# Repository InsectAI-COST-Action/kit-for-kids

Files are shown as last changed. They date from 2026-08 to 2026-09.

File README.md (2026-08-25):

# InsectAI kit-for-kids



An open, DIY insect-camera kit designed to help children aged 8-12 explore insects, ecology, and computer vision through hands-on investigation.

Developed as part of the [InsectAI COST Action](https://www.cost.eu/actions/CA22129/), the project aims to create a classroom-friendly kit that can be built with supervision in around an hour, packaged compactly, and made at scale for under €50. The kit will pair accessible hardware with learning materials for teachers, parents, and young people.

## What we are designing

The kit is being co-designed with educators, researchers, makers, and children. It will support open-ended activities such as observing insect behaviour, testing simple ecological questions, and interpreting results. Proposed hardware includes an ESP32 camera, power bank, and microSD storage, with optional modular components such as habitats, lighting, lenses, or mazes.

AI is intended to support learning, for example by helping to count insects, track movement, recognise patterns, or assist species identification, while keeping its limits visible and leaving interpretation with learners.

## Design principles

- **Children as investigators:** build, observe, test, and interpret.
- **Ecology first:** connect activities to real insects, habitats, and behaviour.
- **Modular and reusable:** adapt the kit for different experiments, lessons, and settings.
- **Low-cost and practical:** robust, portable, and suitable for ordinary classrooms.
- **Open and accessible:** share designs and resources so makerspaces and educators can replicate and adapt them.

## Status

This repository is at the co-design and prototyping stage. Future work will develop and test prototype concepts, refine the hardware and educational resources, and explore suitable on-device and cloud-supported AI approaches.

## Prototype software

- [`software/TomA-insect-ESP32-software`](software/TomA-insect-ESP32-software/): ESP32-S3/OV3660 pilot firmware, SD-card logger, offline dashboard, and accompanying test and operating documentation.
- [`models`](models/): Initial detection models in YOLO26, ONNX, and ESPDet-Pico formats, along with scripts for deploying to ESP32-S3 devices.
- [`datasets`](datasets/): Full training datasets for detection models, with annotations in YOLO format.

## Contributing

We welcome ideas and contributions from educators, children's-learning specialists, entomologists, makers, hardware and software developers, and community organisations. Please open an issue or discussion to propose an experiment, kit feature, learning resource, or collaboration.

## Licence

This project is released under the [MIT License](LICENSE).

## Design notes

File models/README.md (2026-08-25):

# Models

Detection models are currently provided in three formats for testing, [YOLO26](https://github.com/ultralytics/yolo26) as the base format for conversion, [ONNX](https://github.com/onnx/onnx) for browser-based [dashboard](software/TomA-insect-ESP32-software) inference, and [ESPDet-Pico](https://github.com/espressif/esp-detection) for edge deployment on an ESP32-S3. Models are named based upon their corresponding training [dataset](https://github.com/InsectAI-COST-Action/kit-for-kids/tree/main/datasets/) to ensure reproducibility and enable retraining with additional architectures.

## Installation

For simplicity, the YOLO26 and ONNX models can be tested through the standard Ultralytics CLI, however the ESPDet-Pico model must be deployed to an ESP32-S3 via the [deploy](/models/deploy) pipeline. These frameworks are provided for testing rather than integration, and thus should primarily be used for model evaluation. A [test video](/models/test) is provided for this purpose, however additional videos can be uploaded for further validation.

## Usage

### YOLO26

Install Ultralytics.

```bash
python -m pip install ultralytics
```

Run inference on the test video.

```bash
yolo predict model=AntTest.pt source="/models/test/AntTest.mp4"
```

### ONNX

Install Ultralytics.

```bash
python -m pip install ultralytics
```

Run inference on the test video.

```bash
yolo predict model=AntTest.onnx source="/models/test/AntTest.mp4"
```

### ESPDet-Pico

Clone repository.

```bash
git clone https://github.com/InsectAI-COST-Action/kit-for-kids.git
```

Create and activate virtual environment.

```bash
cd kit-for-kids\models\deploy
python -m venv .venv
.\.venv\Scripts\activate
```

Install required packages.

```bash
python -m pip install -r requirements.txt
```

Run script to flash model to ESP32-S3, specifying the port via the `--port` argument.

```bash
python flash.py --port COM4
```

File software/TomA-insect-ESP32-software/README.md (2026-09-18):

# Insect camera logger

> Part of the [InsectAI COST Action Kit-for-Kids](https://github.com/InsectAI-COST-Action/kit-for-kids) project, published at `software/TomA-insect-ESP32-software`. Licensed under the MIT licence of that repository; see its root `LICENSE`. Third-party components carry their own licences — Mediabunny is MPL-2.0 (`dashboard/vendor/mediabunny-LICENSE.txt`) and ONNX Runtime Web is MIT (`dashboard/ai/LICENSE-onnxruntime.txt`). FlatBug's own software is MIT, but its bundled model weights (`dashboard/ai/flatbug-n.onnx`) carry an accepted, not resolved, redistribution risk — see the decision recorded in `docs/model-card.md` before assuming this clears them for further redistribution.

Firmware and an offline dashboard for the Seeed Studio XIAO ESP32S3 Sense with an OV3660 camera. The settled pilot captures and stores every QXGA (2048?1536), JPEG-quality-12 frame at 1 FPS for no more than one hour (3,600 images). Computer vision is deliberately a null adapter on the camera while an offline, browser-side inference path is evaluated.

## Development status

The firmware has been built and uploaded to the physical XIAO ESP32S3 Sense. Boot evidence confirms PSRAM, the OV3660 camera, SD configuration loading, and the null inference adapter. The SD-card recovery path has also been exercised: removing battery power marks the previous run as `interrupted_power_removed`, promotes the open dashboard chunk on the next boot, and keeps the current chunk visible to the offline dashboard.

Historical performance run `run_000012` is an important directory-sharding milestone. Its 2,384 smaller VGA captures used 24 bounded image directories, with all JPEGs and derived dashboard records present. Image-write times stayed effectively flat from 530 ms at frame 100 to 546 ms at frame 2,300; the earlier single-directory runs climbed above 1.7 seconds. It is retained as storage-design evidence, not as acceptance evidence for the settled QXGA/1-FPS pilot.

The dashboard is working as a local file on the SD card. It loads closed chunks plus the current open chunk, shows a compact ten-item preview with working expand/collapse controls, and opens images in an in-page modal. Its child-facing movie maker creates a local, finalized 60-picture-per-second MP4 with an embedded offline MediaBunny encoder, so image decode speed cannot lengthen the video clock. The child-facing shell adds a full-page loading dialogue, a friendly welcome/count, gallery-first exploration, and an experimental local AI journey: the top camera-card folder is selected once, supplying both local pictures and installed FlatBug Nano package or sourced AntAI - Test package. The AI dialogue provides three explicit choices: AntAI - Test (ant-only whole-picture pass), FlatBug - Quick look (whole-picture pass), and FlatBug - Look closely (12 tiled passes); when multiple runs remain on the card, the child chooses one session and analysis never mixes experiments. Pictures are then scanned one at a time with live provisional discoveries and pause/stop controls. This prototype has passed isolated Chrome/Edge model loading, but remains unvalidated and requires dashboard/batch testing. The runtime-generated `manifest.js` and `summary.js` are preserved when `py tools\prepare_sd.py` updates static dashboard files. Host-side contract checks pass.

The QXGA/quality-12/1-FPS setting was selected after controlled card trials: QXGA ran cleanly at 1 FPS, while its 2-FPS stress test delivered only 171 of 240 expected images because JPEG writing alone exceeds the 500 ms budget. See `docs/camera-quality-trial.md`.

The next development path has two strands: child-friendly dashboard/model work and a one-hour QXGA pilot acceptance run. Remaining device acceptance work is the full 3,600-image endurance run, cross-browser verification on Windows 10/11 and current macOS, and a final review of data integrity after repeated power removal. A formal battery-capacity test is deprioritised; a short stability and clean-power-removal smoke test with the intended USB battery pack remains appropriate. These are tracked in `docs/hardware-validation.md` and `docs/next-session.md`.

## Documentation

**New to this project and setting up a camera? Start with the [setup guide](docs/setup-guide.md)** — a complete step-by-step walkthrough written for a non-specialist audience, from installing software to viewing pictures.

[Documentation guide](docs/README.md) is the entry point for operators, developers, browser-model work, and engineering evidence. The detailed [project brief](docs/project-brief.md) remains the implementation-scope contract; [next-session.md](docs/next-session.md) is the current development hand-off.

## Toolchain

Install PlatformIO Core with `py -m pip install platformio`, then run:

```powershell
py -m platformio run
py tests\check_project.py
```

Use `py -m platformio`, not a bare `pio`: it pins PlatformIO to the same Python that runs the helper tools, and a bare `pio` is blocked outright on some managed Windows machines. Installing only the PlatformIO VS Code extension is **not** enough for these commands — `py -m pip install platformio` is still required. The non-specialist walkthrough is [docs/setup-guide.md](docs/setup-guide.md).

The pinned target is `espressif32@7.0.1`, board ID `seeed_xiao_esp32s3`, Arduino framework.

To set up a new device, run `py tools\setup_device.py`: it flashes the firmware to the connected board, then installs the dashboard, folders and default `config.json` on a mounted FAT32 card. Flags `--flash-only`, `--skip-flash --card <root>`, and `--port`/`--card`/`--yes` cover the scripted and partial cases. It is a wrapper around the two steps below, which can also be run directly:

- `py -m platformio run -e xiao_esp32s3 -t upload --upload-port <port>` — flash only.
- `py tools\prepare_sd.py <card-root>` — install or update the static dashboard files; existing runtime `manifest.js`, `summary.js` and `config.json` are left untouched. A fresh card gets `config.example.json` as its `config.json` (the settled QXGA/1-FPS pilot default).

For a separate rehearsal presentation (real reference photos, fabricated run/timing data), run `py tools\install_dashboard_demo.py <card-root>` and open `<card-root>\\demo\\demo.html`.

## Operating flow

1. Insert a FAT32 microSD card containing the dashboard files and `config.json`.
2. Power the battery-operated camera; it captures for a maximum one hour.
3. Disconnect power before removing the SD card. This is the normal stop method.
4. Insert the SD card into a computer and open `dashboard.html` in a supported browser.
5. Delete data manually with the computer's file manager when starting a new experiment.

Do not remove the SD card while the camera is powered. Previous committed records remain recoverable after an unexpected power loss; the device promotes the prior open chunk on the next boot.

## Project map

- `src/` and `include/`: firmware modules.
- `dashboard/`: self-contained HTML/CSS/JavaScript installed on the SD card.
- `dashboard/ai/`: FlatBug Nano, AntAI - Test, and their ONNX Runtime Web runtime; installed by default (see `tools/prepare_sd.py`). Redistribution decision recorded in `docs/model-card.md`. AntAI - Beta was retired 18 September 2026 in favour of AntAI - Test - see `docs/model-card.md`.
- `dashboard/fixtures/`: synthetic local-file data for dashboard testing.
- `tools/setup_device.py`: one-command new-device setup — flash firmware, then prepare the SD card.
- `tools/prepare_sd.py`: install/update the dashboard, folders and default config on a mounted card.
- `tests/check_project.py`: dependency-free contract/static test harness.
- `tools/audit_card.py`: read-only SD-card integrity audit.
- `tools/install_ai_pack.py`: add `dashboard/ai/`'s FlatBug and AntAI - Test package to an older card that predates the default install.
- `tools/train_antai_beta.py`: reproducibly train/evaluate AntAI - Beta from the normalised Roboflow COCO export; weights remain ignored.
- `datasets/ant-detector-rfdetr-v2/`: normalised one-class COCO annotations and provenance for the 49-image AntAI training export; images remain ignored.
- `tools/install_dashboard_demo.py`: install a separate rehearsal presentation demo (real reference photos, fabricated run/timing data - not a real capture session).
- `tools/configure_camera_trial.py`: install or restore a named, short OV3660 quality-trial configuration.
- `tools/camera_trial_report.py`: compare labelled trial-run image sizes, timing, and run state.
- `docs/camera-quality-trial.md`: controlled OV3660 resolution/JPEG/rate comparison.
- `docs/performance-experiment.md`: staged performance-instrumentation protocol.
- `docs/README.md`: documentation map and role-based starting points.
- `docs/`: operations, architecture, model work, and validation evidence.

## Model status

No production CV model has been chosen. `NullInferenceEngine` reports `model_unavailable` and writes no predictions. The current hypothesis is to leave capture on the ESP32 and analyse every retained image later in the local dashboard, protecting capture rate and keeping data offline. FlatBug remains a general-insect candidate, while **AntAI - Test** is a separate experimental one-class ant detector, sourced pre-trained from the published `kit-for-kids` monorepo (18 September 2026, replacing the locally-trained AntAI - Beta - see `docs/model-card.md`). Neither is an approved production dependency. The browser spike and model gates are defined in `docs/browser-inference-plan.md` and `docs/model-card.md`.

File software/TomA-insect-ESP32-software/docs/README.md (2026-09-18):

# Documentation guide

This directory separates everyday operation from technical design and historical evidence. Start with the shortest document that fits your role; do not treat every document as a current task list.

## Start here

| If you are... | Read | Purpose |
| --- | --- | --- |
| Setting a camera up for the first time | [Setup guide](setup-guide.md) | Complete step-by-step from installing software to viewing pictures, written for a non-specialist (teacher-level) audience. |
| Preparing, running, or collecting from the camera | [Operations guide](operations.md) | SD-card preparation, normal operation, browser dashboard, AI prototype, recovery, and cleanup. |
| Returning to development | [Next session checklist](next-session.md) | Current hand-off state and the prioritised next tasks. |
| Preparing the Barcelona show-and-tell | [Barcelona demo runbook](barcelona-demo.md) | Working source for the printable demo-day guide; what's built, what's missing, outstanding blockers. |
| Looking for the project overview | [Repository README](../README.md) | What exists, current status, basic commands, and project map. |
| Publishing local commits to GitHub | [CLAUDE.md](../CLAUDE.md) | This repo has no git remote by design — it publishes into the `kit-for-kids` monorepo via `git subtree` from a separate clone. Read this before assuming a commit here is visible upstream. |

## System reference

| Document | Authority |
| --- | --- |
| [Project brief](project-brief.md) | Detailed scope contract and requirements for implementation agents. It is not the day-to-day operating guide. |
| [Architecture](architecture.md) | Component boundaries and data-flow decisions. |
| [Decision records](adr/) | Numbered ADRs. A decision that changes scope or a shared contract is recorded here before the work starts. |
| [Data schema](data-schema.md) | Capture, run, and derived-dashboard record formats. |
| [Camera specification](camera-spec.md) | Confirmed OV3660/XIAO hardware and power facts. |
| [OV3660 image-quality trial](camera-quality-trial.md) | Controlled resolution/JPEG/rate comparison and decision rule. |
| [Operations guide](operations.md) | Human operating procedure; use this for SD-card handling. |
| [Serial development bridge](dev-bridge.md) | Inspecting and changing the SD card over USB serial while it stays in the board, for unattended/remote development. |

## Browser AI and model work

| Document | Purpose |
| --- | --- |
| [Browser inference plan](browser-inference-plan.md) | Architecture, child-facing behaviour, technical evidence, and acceptance gates for offline browser analysis. |
| [Model card](model-card.md) | Candidate/prototype record and the evidence required before model approval. |

The current FlatBug Nano and AntAI - Test routes are browser prototypes only. It must be described as a **possible-insect prediction**, not species identification or a validated detection result.

## Engineering evidence and history

| Document | Purpose |
| --- | --- |
| [Device control app plan](device-control-app-plan.md) | Phased implementation plan and acceptance gates for the Wi-Fi control app ([ADR 0001](adr/0001-device-hosted-control-app.md)). |
| [Hardware validation](hardware-validation.md) | Board, card, and browser verification record. |
| [Performance experiment](performance-experiment.md) | Storage/capture timing investigation and the run-000012 sharding milestone. |
| [Reconciliation policy](reconciliation-policy.md) | Rules for auditing, rebuilding, and manually cleaning SD-card data. |

## Experiment files and generated evidence

- `spikes/` holds small, tracked, reproducible technical experiments and their instructions. It must not contain camera photos, model weights, or generated reports.
- `artifacts/` is Git-ignored and holds local generated evidence: reports, contact sheets, model downloads, training output, and abandoned trial output. It may be safely recreated from the relevant source workflow when appropriate.
- The motion-trigger experiment is documented in [`../spikes/motion-detection/`](../spikes/motion-detection/README.md). Its 19 August 2026 sample evidence is local-only under `artifacts/motion-detection/`.

## Documentation rules

- Keep the README short and link here rather than repeating detailed requirements.
- Update `next-session.md` at the end of a development session; it is the current hand-off, not a permanent specification.
- Record decisions and acceptance criteria in the relevant design document rather than copying them into several status sections.
- Preserve measured results in their evidence document. Do not delete historical tests merely because the current approach has moved on.
- A future GitHub Pages site should use this file as its landing-page structure, but publishing is deliberately deferred until the documentation review is complete.

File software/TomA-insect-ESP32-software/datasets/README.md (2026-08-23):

# Local computer-vision datasets

Dataset layouts, split manifests, annotation guidance, and labels are tracked here. Source images are intentionally ignored by Git because camera datasets can be large and may require separate review before any public sharing. Use `tools/build_ant_detector_dataset.py` to recreate an image split from a mounted card.

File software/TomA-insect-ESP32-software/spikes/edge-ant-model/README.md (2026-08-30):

# Edge ant model spike

Feasibility spike for [ADR 0002](../../docs/adr/0002-on-device-ant-edge-model.md): can this project's firmware build ESP-DL (Espressif's on-device deep-learning library) alongside the existing Arduino-framework capture pipeline, to run a collaborator's ESPDet-Pico ant model (`AntTestModel.espdl`, `models/ESPDet-Pico/` in the upstream `kit-for-kids` monorepo) on-device?

## Status, 30 August 2026: blocked on a machine-specific policy, not a technical dead end

Step 1 (does `framework = arduino, espidf` even build for this board, before adding ESP-DL) hit two issues, in order:

**1. ESP-IDF's CMake/ninja build tooling does not tolerate spaces in the project path.** This project's real path (`G:\My Drive\InsectAI - Core Group\WG 2\...`) has several. The pure-`arduino`-framework main firmware has never hit this because its SCons-based build doesn't need external CMake at all - this is specific to the ESP-IDF side of a mixed build. **Fixed** by mirroring the spike to a clean path, `C:\k4k\edge-ant-model-spike\` (same reasoning as the existing subtree publishing clone at `C:\k4k\kit-for-kids`).

**2. From the clean path, PlatformIO successfully resolved and downloaded the full ESP-IDF toolchain** (tool-idf, tool-cmake, tool-ninja, toolchain-xtensa-esp32s3, etc.) - real, positive evidence that this project's exact platform/board (`espressif32 @ 7.0.1`, `seeed_xiao_esp32s3`) supports the mixed `arduino, espidf` framework combination in principle. It then failed invoking `tool-cmake`'s `cmake.exe` (`C:\Users\tomaug\.platformio\packages\tool-cmake\bin\cmake.exe`) with `OSError: [WinError 4551] Your organization used Device Guard to block this app.` This is the **same class of restriction** already documented in `docs/next-session.md`'s PlatformIO toolchain note (which blocks the `pio.exe`/`platformio.exe` launcher stubs) - but a *different* binary, newly encountered because the pure-Arduino build never needed a standalone CMake before. `py -m platformio` (the existing workaround for the launcher-stub case) does not help here; the block is on `cmake.exe` itself, not on how PlatformIO is invoked.

**This means the ESP-DL/Arduino integration question itself remains open** - genuinely promising so far (no architecture incompatibility found; the toolchain resolves and downloads cleanly), but unproven, because the build cannot get past this machine's security policy to actually compile anything yet.

## Options, not yet acted on

1. **Request an IT/Device Guard exception** for `C:\Users\tomaug\.platformio\packages\tool-cmake\bin\cmake.exe` specifically (and likely other binaries under `tool-idf`/`tool-ninja`/the toolchain packages, once this one is past) - the same category of request that presumably already exists for the signed `py` launcher.
2. **WSL2 with a Linux distro.** Device Guard is a Windows-native code-signing/execution policy; it would not apply inside a Linux subsystem. Checked 30 August 2026: `wsl.exe` is present but no distro appears installed - this is a real setup task (likely needs admin rights to enable), not a quick win, but would probably sidestep this entire class of restriction for good, not just this one binary.
3. **Build on a different, unrestricted machine and transfer the compiled firmware.** The colleague who built `AntTestModel.espdl`/`AntTestModel.bin` has *already* solved an ESP-DL toolchain setup, on some machine. Flashing the resulting `firmware.bin` here only needs `esptool.py`, already proven working all day over the dev bridge/direct upload - no CMake involved at all on this machine for that step.

## Files

- `platformio.ini` / `src/main.cpp` - the minimal step-1 test (mixed framework, no ESP-DL yet). Kept as the starting point for whichever option above unblocks the build.
- Not committed: the mirrored clean-path copy at `C:\k4k\edge-ant-model-spike\` (outside this repo, local-only) and the model weight itself (`AntTestModel.espdl`, fetched from the upstream `kit-for-kids` clone when needed - not tracked in this repo, matching the existing FlatBug asset convention).

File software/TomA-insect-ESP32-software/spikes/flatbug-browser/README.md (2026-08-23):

# FlatBug browser feasibility spike

This folder records the offline browser-model feasibility work. It is not a validated detector and is not part of the ESP32 firmware.

## Active route: `picker.html`

Open `picker.html` with `file://` in Chrome or Edge, choose this folder, then choose one test image. The page loads ONNX Runtime Web through browser File objects and Blob URLs, using WebAssembly only. It runs a single 640x640 letterboxed FlatBug Nano ONNX pass, applies provisional box filtering, and labels results as **possible insects**.

The associated dashboard implementation uses the same technique, but asks an adult to select the top camera-card folder once. This supplies both the saved images and the local `ai/` package without uploading data or running a server.

## Local model policy

Model weights and ONNX exports are intentionally ignored by Git. The current local technical artefact is FlatBug v1.0.0 Nano exported as `assets/flatbug-n.onnx` (11,906,627 bytes; SHA-256 `ec75aeb85b42c86663b006f650681a2d5728d89cff096deaefc09ef371bd9d71`). Confirm weight redistribution rights before including any model bytes in an open-source release.

The bundled runtime files retained in Git come from the MIT-licensed `onnxruntime-web` 1.27.0 package. Other downloaded runtime variants remain ignored because the current WASM route does not use them.

## Historical direct-load diagnostic

`spike.html` records the earlier direct `file://` loading attempt. It failed in Edge because the runtime's dynamic module import was blocked. The failure and its replacement architecture are recorded in `docs/browser-inference-plan.md`; the folder-selection route is the active one.

Sources: https://github.com/darsa-group/flat-bug/ and https://onnxruntime.ai/docs/get-started/with-javascript/web.html

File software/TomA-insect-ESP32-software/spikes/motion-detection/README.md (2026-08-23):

# Motion-detection spike

This tracked experiment evaluates a lightweight on-device pre-trigger policy without changing an SD card. It compares consecutive camera JPEGs as 160 x 120 grayscale previews, removes the global brightness shift, divides the image into 8 x 6 tiles, and takes the strongest tile mean absolute difference as the motion score.

Run it against a mounted card with a bounded sample before changing the threshold:

```powershell
py spikes\motion-detection\motion_detection_spike.py D:\ --pairs-per-session 100 --output artifacts\motion-detection\YYYY-MM-DD-sample
```

The accepted first threshold is **5**. On the 19 August 2026 100-pair-per-session sample, it retained 9/100 comparisons from run_000008 and 6/100 from run_000009. This is a tuning starting point, not a validated detection result. Generated reports, contact sheets, and interrupted trial output belong under ignored `artifacts/motion-detection/`; this folder contains only reproducible code and instructions.

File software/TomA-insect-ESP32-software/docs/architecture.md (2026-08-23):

# Architecture

By default, the main loop targets one QXGA/JPEG-quality-12 frame every 1,000 ms, passes it to the inference interface, writes the original JPEG, appends an authoritative capture CSV row, and returns the frame buffer on every outcome path. The optional experimental motion policy waits five seconds after boot, retains its first full JPEG, then captures 160 x 120 grayscale previews on each scheduled attempt. It subtracts global brightness drift, scores the strongest of 8 x 6 tiles, and retains a full configured JPEG only at score 5 or higher. After a retained JPEG, two internal grayscale settling frames establish a fresh baseline so mode-switch exposure changes are not mistaken for motion; every scheduled preview still receives an authoritative CSV row. During the browser-inference feasibility phase, the on-device interface remains the null adapter and records `model_unavailable`; it must not delay capture. A complete one-hour QXGA/1-FPS endurance acceptance run remains pending.

`CameraService` owns `esp_camera`; `SdStorage` owns the SD filesystem; `SessionLogger` owns IDs, CSV rows, and run manifests; `DashboardWriter` owns only derived JavaScript chunks and summaries; and `IInferenceEngine` hides model-specific code. No module other than `CameraService` can call `esp_camera_fb_get`.

Raw CSV is authoritative. JPEGs are atomically written beneath `/images/<run>/shard_<nnnn>/`, with a new shard every 100 captures to bound FAT directory growth. Dashboard chunks are immutable after promotion from `.part` to `.js`; `manifest.js` lists only promoted chunks. An interrupted partial chunk is deliberately unreferenced, so it cannot break `dashboard.html`.

## Provisional inference split

The next technical spike moves production-model execution out of the ESP32 capture loop and into the offline dashboard after the SD card is inserted into a computer. This is a provisional architecture, not an accepted model implementation:

1. The ESP32 captures and safely stores every frame at the configured cadence.
2. The dashboard loads the session without starting inference, so the user can explore the pictures immediately.
3. A large, explicit child-friendly action starts local analysis of retained images.
4. A locally bundled browser runtime and model process images without network access. The UI reports progress, remains cancellable and responsive, and makes model uncertainty clear.
5. Results use the existing versioned prediction contract where possible. The first portable implementation may offer a download rather than write back to the SD card, because cross-browser local-file write access is not assumed.

ONNX Runtime Web with WebAssembly is the baseline runtime to test across Chrome, Edge, Firefox, and Safari. WebGPU may be an optional acceleration path where supported, but must not be required. `file://` loading of the model, WebAssembly assets, workers, and image files must be proven in the full browser matrix before this architecture is accepted. See `docs/browser-inference-plan.md`.

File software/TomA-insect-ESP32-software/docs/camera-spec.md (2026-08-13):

Specifications
Processor	ESP32-S3R8
Xtensa LX7 dual-core, 32-bit processor that operates at up to 240 MHz
Wireless	Complete 2.4GHz Wi-Fi subsystem
BLE: Bluetooth 5.0, Bluetooth mesh
Built-in Sensors	ov3660
Digital microphone
Memory	On-chip 8M PSRAM & 8MB Flash
Onboard SD Card Slot, supporting 32GB FAT
Interface	1x UART, 1x IIC, 1x IIS, 1x SPI, 11x GPIOs (PWM), 9x ADC, 1x User LED, 1x Charge LED,
1x B2B Connector (with 2 additional GPIOs)
1x Reset button, 1x Boot button
Dimensions	21 x 17.5 x 15mm (with expansion board)
Power	Input voltage (Type-C): 5V
Input voltage (BAT): 4.2V
Circuit operating Voltage (ready to operate):
- Type-C: 5V@38.3mA
- BAT: 3.8V@43.2mA (with expansion board)
Webcam Web application:
- Type-C:
- - Average power consumption: 5V/138mA
- - Photo moment: 5V/341mA
- Battery:
- - Average power consumption: 3.8V/154mA
- - Photo moment: 3.8V/304mA
Microphone recording & SD card writing:
- Type-C:
- - Average power consumption: 5V/46.5mA
- - Peak power consumption: 5V/89.6mA
- Battery:
- - Average power consumption: 3.8V/54.4mA
- - Peak power consumption: 3.8V/108mA
Charging battery current: 100mA
Low Power Consumption Model	Without any peripherals:
- Modem-sleep Model: 3.8V/25.5 mA
- Light-sleep Model: 3.8V/2.4 mA
- Deep Sleep Model: 3.8V/63.768 μA
Connect the camera:
- Modem-sleep Model: 3.8V/44.57 mA
- Light-sleep Model: 3.8V/5.47 mA
- Deep Sleep Model: 3.8V/3.00 mA
Connecting an SD Card:
- Modem-sleep Model: 3.8V/32.8 mA
- Light-sleep Model: 3.8V/3.48 mA
- Deep Sleep Model: 3.8V/1.08 mA
Simultaneously connect the camera and the SD card:
- Modem-sleep Model: 3.8V/55.72 mA
- Light-sleep Model: 3.8V/6.56 mA
- Deep Sleep Model: 3.8V/3.98 mA
Wi-Fi Enabled Power Consumption	Active Model: ~ 110 mA (with expansion board)
BLE Enabled Power Consumption	Active Model: ~ 102 mA (with expansion board)
Working Temperature	-40°C ~ 65°C

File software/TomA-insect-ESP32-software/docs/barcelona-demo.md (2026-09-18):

# Barcelona demo Instructions

**Event:** show-and-tell, week of 7 September 2026. Audience: children, assembling and running the device themselves.

**Planned sequence** (owner's own words, 31 August 2026): children assemble the physical device → place a reference image (ants) underneath → run a ~1 minute experiment → connect a phone to see it working → remove the SD card, put it in a computer, and see the AI results.

This document is the working source/runbook a facilitator can follow. The printable child/teacher-facing guide (and its PDF) is a separate document — see "The printable guide" at the bottom.

---

## What's already built vs. what's missing

| Step | Status |
| --- | --- |
| 1. Physical assembly (board, camera, frame) | **Out of scope for this document.** This repository is the *software* side only (see [CLAUDE.md](../CLAUDE.md), [setup-guide.md](setup-guide.md): "The enclosure — Not covered here"). Assembly steps must come from the enclosure subgroup's own materials. Placeholder left below. |
| 2. Place the reference image, power on, run ~1 minute | Built and validated - this is just "collect a session" from [operations.md](operations.md), using the pilot default (retain-every-frame, QXGA, 1 FPS). |
| 3. Connect a phone, see it working | Built - the device-hosted control app ([ADR 0001](adr/0001-device-hosted-control-app.md)). **Confirmed working on Android** (QR scan → auto-join → captive-portal opens the app, no IP address needed). iPhone is untested - not a known bug, just never tried on real hardware. **Recommendation: bring an Android phone as the primary device for this step.** |
| 4. SD card → computer → AI results | Built - `dashboard.html`, fully offline, works in Chrome/Edge/Firefox/Safari. A zero-risk **rehearsal mode** already exists (`install_dashboard_demo.py`) using real reference photos with fabricated run/timing data, so this step can be fully practiced beforehand without touching a real card. |

## One important constraint for step 2+3 together

**Wi-Fi and motion-triggered capture cannot run at the same time** - Wi-Fi activity causes a 100% false-trigger rate in motion detection (documented, [device-control-app-plan.md](device-control-app-plan.md)). This is not a problem for the demo: use the **retain-every-frame** mode (the pilot default), which has no motion comparison to disturb. Do not enable "Save pictures only when something moves" for this demo.

## Step-by-step (software side)

### Before the day: prepare the card
1. `py tools\prepare_sd.py <card-root>` on a fresh or wiped FAT32 card (≤32 GB).
2. `py tools\configure_camera_trial.py <card-root> --install-pilot-default` - confirms retain-every-frame QXGA mode, not motion-trigger.
3. Rehearse the AI-review step risk-free first: `py tools\install_dashboard_demo.py <card-root>`, open `<card-root>\demo\demo.html` (opens already loaded - no folder to choose), run through **Start looking** and **Make my insect movie** so whoever facilitates has done it once already.

### On the day
1. *(Physical assembly - see enclosure subgroup materials.)*
2. Place the reference image under the camera.
3. Connect the battery cable. The device is now capturing.
4. Hand a phone to a child. Join this unit's own Wi-Fi network from the phone's Wi-Fi settings — name it **`InsectCam-` + the label on this enclosure** (see "The Wi-Fi network name" below), password **antcamera**. The control app should open automatically; if not, browse to `192.168.4.1`.
5. On the control app: **👁️ Take a peek** shows the most recent photo live. Let the pictures accumulate for about a minute.
6. Tap **🏁 Finish my adventure** - this safely stops and unmounts the card. Wait for its confirmation before touching the card.
7. Disconnect the battery cable, remove the SD card, insert it into a computer.
8. Open `dashboard.html` from the card. Show the captured images, then **Find insects with AI** (FlatBug - Quick look is fastest) to show the AI results on the real session just captured.

### The Wi-Fi network name

As of 17 September 2026 each board's Wi-Fi network name is unique - `InsectCam-` plus 3 characters derived from that board's own chip ID, computed automatically at boot (see [device-control-app-plan.md](device-control-app-plan.md), "Phase 5 amendment"). `py tools\setup_device.py` prints the exact name right after flashing; **label the enclosure with it** so a child (or a facilitator with several units in the room) can find the right one in the phone's Wi-Fi list without guessing. QR-code joining was dropped along with the old single shared SSID - it would have meant a unique sticker per unit, the exact cost the original shared-credentials decision was trying to avoid. `docs/assets/insectcam-wifi-qr.png` still exists but is no longer part of the instructed flow.

## Outstanding before this is demo-ready

1. **A real end-to-end rehearsal** of the exact sequence above, timed, on the actual hardware that's travelling to Barcelona - not yet done as of this writing. See "Stability check" below.
2. **Firmware is a normal pilot build** (the white-balance seeding work is finished - see hardware-validation.md). Daylight-confirmed 2 September 2026: a real, visible improvement over the original green/purple casts, but a mild residual purple/mauve tint remains in shadowed areas - not a clean neutral pass. Worth knowing for the demo: photos won't have the old strong cast, but don't expect perfectly neutral colour either.
3. Physical assembly instructions - need to come from the enclosure subgroup, not written here.
4. iPhone path is genuinely untested. If any child is likely to bring an iPhone, worth a quick real test beforehand rather than finding out live.
5. Label the enclosure with its Wi-Fi network name (see "The Wi-Fi network name" above) - no QR code to print any more, but the name still needs to be on the unit before the day, not just in a terminal scrollback.

## The printable guide

Built, 14 September 2026: [`barcelona-demo-guide.html`](barcelona-demo-guide.html) (+ [`barcelona-demo-guide-es.html`](barcelona-demo-guide-es.html), cross-linked with each other) and their PDFs, rendered via `msedge.exe --headless=new --print-to-pdf`, matching this project's existing headless-Chrome pattern. Both versions carry real photos of the actual build sequence and the actual control-app screens (supplied by the owner), not placeholders. Spanish button wording (`👁️ Echa un vistazo`, `🏁 Termina tu aventura`) matches the phone app's own translated text exactly - see the language-support entry in [next-session.md](next-session.md).

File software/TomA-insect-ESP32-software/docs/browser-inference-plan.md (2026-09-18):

# Child dashboard and offline browser inference plan

Status: child dashboard and FlatBug Nano browser-analysis prototype implemented; production acceptance remains decision-gated
Recorded: 13 August 2026

## Outcome

Keep the ESP32 focused on reliable one-frame-per-second QXGA/JPEG-quality-12 capture and SD-card persistence. After collection, let the user open `dashboard.html` and deliberately start insect analysis on the computer. All inference must remain local and offline; images must not be uploaded.

This path is provisional. It supersedes the earlier assumption that the first production model must execute after each capture on the ESP32, but it does not yet approve a browser runtime or model. Every retained frame remains eligible for analysis.

## Child-first dashboard direction

The main experience is for a supervised young child, while technical details remain available to an adult:

- show a large, friendly full-page loading panel while session data is being read, with plain-language progress and a useful error/retry state;
- make the primary choices obvious, such as **Explore pictures** and **Find insects with AI**;
- use large touch targets, strong contrast, fun but restrained colours, short instructions, keyboard support, visible focus, non-colour status cues, and reduced-motion support;
- do not start model analysis during initial page loading;
- while analysing, show the current picture, progress through the session, discoveries so far, elapsed/estimated time only when trustworthy, and obvious pause/cancel controls;
- make the process engaging without disguising waiting, errors, or uncertainty; and
- consistently say **label**, **class**, **prediction**, or **possible insect**. Explain that AI can make mistakes and do not imply species identification.

The existing compact frame/gallery views, expand controls, modal image viewer, session-relative time, and adult health information should be retained or improved rather than removed.
## Implemented browser-analysis prototype (15 August 2026)

`dashboard/analysis.js` now provides the first child-facing analysis journey in the dashboard. It is a prototype, not validated detection or a production release:

1. The child selects **Find insects with AI** and sees a short explanation that predictions can be wrong.
2. An adult chooses the **top camera-card folder** once. The browser reads both its saved pictures and the FlatBug Nano ONNX/ONNX Runtime Web assets from that selected folder as File objects; it does not upload pictures, use a server, or make a network request.
3. The child presses **Start looking**. The dashboard processes saved images one at a time, yields between pictures, shows the current image with a moving scanner, changes friendly explanatory text, and immediately adds a card whenever a provisional possible-insect box appears.
4. Clear **Pause search** / **Keep looking** and **Stop search** controls remain available. The summary reports checked images, possible-insect image count, and any read/inference failures. Results remain in browser memory only and do not alter the authoritative SD-card records.

The current offline package contains ONNX Runtime Web WebAssembly with one thread plus two experimental models. The child makes one clear choice before starting:

- **AntAI - Test**: a one-class ant detector, one 640x640 whole-picture pass. Replaced AntAI - Beta 18 September 2026 - see `docs/model-card.md`.
- **FlatBug - Quick look**: FlatBug Nano, one 640x640 whole-picture pass for larger or clearer insects.
- **FlatBug - Look closely**: FlatBug Nano, 12 overlapping native-scale 640x640 tiles for a normal QXGA image, 4 across by 3 down, for tiny insects.

The FlatBug output is a segmentation tensor with four box channels, one insect-confidence channel, and 32 mask-coefficient channels. The browser must read only the insect-confidence channel; interpreting the coefficients as scores caused an August 2026 false-positive/over-100-percent display defect and is now covered by a regression check. All three paths merge duplicate boxes, retain small candidates, and remain experimental. The selected top camera-card folder must contain `ai/flatbug-n.onnx`, the runtime files, and `ai/antai-test.onnx`. As of 18 September 2026 all three ship by default with `py tools\prepare_sd.py <card-root>` (see the redistribution decision in `docs/model-card.md`); `py tools\install_ai_pack.py <card-root>` adds them to an older card. Chrome/Edge folder-picker evidence exists; Firefox/Safari, the FlatBug redistribution review itself, representative-image validation, batch performance, persistence/export, and the 3,600-image feasibility gate remain open.

## Technical hypothesis

- Package the model, runtime and all UI assets on the SD card. No CDN, server, installation, account, analytics, or internet connection is allowed.
- Prototype ONNX Runtime Web with WebAssembly as the portable baseline. Treat WebGPU as optional acceleration, never as the only route.
- Continue supporting direct `file://` use in current Chrome, Edge, Firefox, and Safari on Windows 10/11 and current macOS.
- Prove local loading of model/WASM/worker assets and JPEGs in every target browser; do not assume behaviour that only works over HTTP.
- Process images incrementally in bounded batches, yield to the UI between batches, avoid retaining decoded full-resolution images, and provide pause/cancel and recoverable failure states.
- Keep camera data local. The first cross-browser result persistence method may be a clearly named CSV/JSON download. Direct write-back to the SD card is optional and cannot be required unless it is proven safe and simple across all target browsers.
- Version browser-produced predictions and preserve model ID/hash, settings and source capture IDs. Never alter the authoritative capture log in place.

## Preferred candidate: FlatBug

Evaluate FlatBug first if its official model artefacts can be obtained and licensed for this distribution. FlatBug is designed for general terrestrial arthropod detection and segmentation and uses YOLOv8 plus a custom pyramid/tiling workflow. The reference software is Python/PyTorch oriented and its published hardware guidance begins above 2 GB VRAM, so browser feasibility cannot be assumed. Exact weight size, supported export, tiling cost and accuracy on enclosure imagery must be measured.

Sources:

- https://asgersvenning.com/flat-bug/
- https://github.com/darsa-group/flat-bug/

If the full reference pipeline is too large or slow, make an explicit decision among:

1. use a smaller official FlatBug variant;
2. export/quantise or adapt it, with a new identity and measured accuracy change;
3. train or fine-tune a smaller one-class insect detector using appropriately licensed data; or
4. reject browser inference if it cannot meet the user journey.

Do not label a derived or replacement model as FlatBug without permission and accurate provenance.

## Feasibility experiment

Use a fixed representative set of at least 100 enclosure images, including empty frames and difficult conditions. Record:

- model/runtime bytes and browser peak memory;
- dashboard data-load time separately from model-load time;
- time to first prediction, median/p95 per-image time, total batch time, errors, and cancellation behaviour;
- agreement with the reference Python pipeline on the same images;
- detection quality before and after any export, quantisation, resizing, or tiling change;
- UI responsiveness and child-facing comprehensibility; and
- results for each required OS/browser combination, with WebAssembly results mandatory and WebGPU results supplementary.

Extrapolate the measured batch time and memory behaviour to a maximum 3,600-image session. Do not require analysis to match the camera's real-time 1 FPS capture rate; instead, agree a child-appropriate post-session wait-time target after the first benchmark. Do not auto-skip frames to meet it.

## Acceptance gate

Browser inference becomes the production direction only when:

- the offline `file://` package works without security-setting changes in the required browser matrix;
- the complete package size and analysis time are practical for the SD card and reference computers;
- the UI stays responsive, cancellable and understandable;
- results are reproducible, versioned, privacy-preserving and exportable;
- the model/dependencies/data are legally redistributable in the open-source project; and
- representative-image validation supports the exact claims shown to users.

Until then, firmware continues to record `model_unavailable`, and the dashboard must not display synthetic or unvalidated predictions as real observations.

## FlatBug `file://` loading result (14 August 2026)

A reproducible isolated spike is at `spikes/flatbug-browser/`. The official FlatBug v1.0.0 medium checkpoint was exported locally to a structurally valid 98.5 MB ONNX segmentation model (opset 18). The model remains ignored by Git pending confirmation that its weights may be redistributed.

The `file://` compatibility gate **did not pass in current Microsoft Edge**. The page, local ONNX model, and all ONNX Runtime Web 1.27.0 WebAssembly assets were present. However, ONNX Runtime Web dynamically imports its `.mjs` helper from its classic browser bundle, and Edge rejects that dynamic local module import from a direct local-file page. Explicit absolute `file://` asset paths and the WASM-only classic bundle produced the same failure. The ESM bundle also did not execute from the direct local-file page.

The direct-import route remains a regression diagnostic, but it is no longer the chosen architecture. The successful replacement is the single top-camera-card folder selection: it supplies both the local `ai/` assets and saved image File objects, which are loaded through Blob URLs and `createImageBitmap()`. This path is implemented in `dashboard/analysis.js` and has working Chrome/Edge evidence. It remains a prototype, not a production acceptance result.

## AntAI - Beta (retired 18 September 2026, replaced by AntAI - Test)

AntAI - Beta was a one-class, locally trained YOLO26 Nano ant detector, separate from FlatBug Nano. It was trained from the updated 49-image Roboflow COCO export (34 train, 10 validation, 5 held-out test images), with the source labels `ant` and `ants` deliberately merged into one `ant` class.

Retired from the shipped dashboard 18 September 2026 in favour of AntAI - Test - `dashboard/ai/antai-beta.onnx` has been deleted and no installer references it any more. Kept here as the historical record of what was built and why; see `docs/model-card.md`'s AntAI - Beta record for the full detail and `docs/model-card.md`'s AntAI - Test record for its replacement.

When a card contains multiple saved runs, both the movie maker and AI dialogue default to the newest available session and provide a session selector. AI analysis reads only the selected run; it does not silently mix pictures from different experiments. (This behaviour is unchanged by the AntAI - Test swap.)

## Future direct-write phone dashboard route

The intended phone workflow is to plug the powered-off camera board directly into a phone and have the board expose its physical SD card as USB storage. The dashboard should then request the card folder once and be able to write clearly confirmed, validated changes - for example `config.json` and later exported AI results - back to that card. It must retain the offline/no-upload guarantee.

This is a feasibility gate, not a current supported workflow. Direct browser file writes depend on browser and operating-system permission models; desktop Chrome/Edge evidence cannot be treated as proof for a phone. Test the exact target Android/Chrome and iPhone/Safari combinations with the locally opened dashboard, an explicit folder/write permission, a configuration write, and a reboot verification. Do not replace this with an external-reader/manual-copy journey if the test fails; return for an architecture decision.

The board side is an ESP32-S3 USB Mass Storage Class (MSC) feasibility spike. It requires a strict state transition between camera ownership of the SD filesystem and USB-host ownership: stop capture, flush/unmount, expose storage, detect disconnect, then remount/reconcile. It must never capture while a phone can access the card. Validate device power, filesystem integrity, interrupted-disconnect recovery, and repeated hand-offs before offering it to children. Automatic dashboard launching on attachment should be investigated separately and cannot be promised until it works on the actual phones.

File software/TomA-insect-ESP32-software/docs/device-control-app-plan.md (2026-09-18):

# Device control app: technical plan

Implementation plan for the device-hosted control app authorised by [ADR 0001](adr/0001-device-hosted-control-app.md). Read that first for scope boundaries and what this deliberately excludes.

This is a working plan with acceptance gates, not a specification of finished behaviour. Update it as phases complete.

## Design principles

1. **The control app carries control data only.** Status, configuration, lifecycle commands, and at most one still frame at a time. Bulk image data never crosses Wi-Fi.
2. **The capture loop owns the SD card.** HTTP handlers never touch the card, the camera, or the logger directly.
3. **The card workflow never depends on the network.** If Wi-Fi fails entirely, the device still captures and the SD dashboard still works.
4. **The firmware remains the final validator.** The app may only offer configurations the firmware accepts, and the firmware re-validates on boot regardless.

## Architecture

### Concurrency: command queue, single SD owner

HTTP handlers run in the web-server task; capture runs in the main loop. Rather than guarding the SD card with mutexes — where lock ordering is easy to get wrong and the cost of an error is a corrupted card — handlers **enqueue a command and return immediately**. The main loop drains the queue *between* captures, so commands can only take effect at points already known to be safe.

```
HTTP task                     Main loop (single SD owner)
---------                     ---------------------------
POST /api/stop
  push CMD_STOP  ----------->  ... finish in-flight capture
  return 202 Accepted          drain queue
                               CMD_STOP -> finishSession() -> SD.end()
                               state = SAFE_TO_REMOVE
GET /api/status
  read status struct <-------  main loop publishes status each cycle
  return JSON
```

Status is a small struct the main loop republishes each cycle; handlers only read it. The one shared buffer needing care is the peek frame (below).

**Implementation note (Phase 2):** with a synchronous single-task `WebServer` (see Network, below), the HTTP handler and the main loop already never run concurrently, so the "queue" for the one command implemented so far (`CMD_STOP`) is a single `volatile bool` set by the handler and consumed once by the main loop between captures — no actual FreeRTOS queue was needed. Revisit if a real queue becomes necessary once multiple command types exist.

### The UI lives in flash, not on the card

The control app is embedded in the firmware binary and served from flash. This matters for a specific reason: **after a safe stop the card is unmounted**, and that is exactly the moment the UI must still be able to say "safe to unplug now". Serving it from the card would make the interface disappear at its most important moment. It also removes SD reads from the serving path entirely.

Budget: the current build uses 11.2% of a 3.67 MB application partition, so there is ample room. Target under 30 KB uncompressed, served gzipped.

**Hard constraint:** a phone joined to the camera's AP has **no internet**. No web fonts, no CDN, no external resources of any kind — the same discipline the SD dashboard already follows. System fonts only.

### Preview frames from PSRAM

"Take a peek" serves **the most recent captured frame, retained in PSRAM** — not a fresh capture. This costs no SD read and no camera reconfiguration; at a one- or two-second interval it is effectively live. The frame is copied to a PSRAM buffer immediately after capture (roughly 100 KB at QXGA, a few milliseconds against a 1,000 ms budget).

Use **double buffering** with an atomic index swap so a peek request cannot read a buffer the capture loop is overwriting.

An explicit **"fresh photo"** action remains available for long capture intervals, but it is a queued command, not a direct handler action, and carries two rules:

- A peek is **never written to the card and never logged as a capture.** `captures.csv` remains the record of scheduled captures only.
- If motion mode is enabled, a fresh capture **must re-baseline the motion preview afterwards** (the existing `refreshMotionBaseline()` settle path). Skipping this causes a false motion trigger on the very next check — the failure mode already documented in the motion-detection work.

### Network

- **SoftAP**, WPA2-protected. An open AP would let any nearby device stop a run.
- SSID derived from the device MAC: `InsectCam-XXXX`, so multiple kits in one classroom do not collide.
- Fixed IP `192.168.4.1`. Do **not** depend on mDNS/`.local` — unreliable on Windows without Bonjour.
- **Implemented with `WebServer` from the Arduino-ESP32 core** (synchronous, single-task), not raw `esp_http_server` as originally planned. No new PlatformIO dependency either way; `WebServer` was simpler to reach for in the Arduino framework and its synchronous, one-request-at-a-time model is exactly what the single-SD-owner design wants — handlers run to completion on the same task as capture, so a plain flag does the job a command queue was planned for. Revisit only if concurrent-request handling becomes a real need.

### Access via QR code

The enclosure carries a printed QR code encoding Wi-Fi credentials in the standard format, which both iOS and Android join directly from the camera app:

```
WIFI:S:InsectCam-A7B3;T:WPA;P:<device-password>;;
```

A captive-portal DNS responder then redirects the phone's automatic connectivity check to the control app, so the page opens without anyone typing an IP address. Captive-portal behaviour varies across platforms, so `192.168.4.1` must remain documented as the fallback and be printed alongside the QR code.

## HTTP interface

Small, boring, and stable. All responses JSON except `/` and `/api/peek`.

| Method | Path | Purpose | Notes |
| --- | --- | --- | --- |
| `GET` | `/` | Control app | From flash, gzipped |
| `GET` | `/api/status` | State, counts, elapsed time, recent motion scores | Polled every ~2 s |
| `GET` | `/api/peek` | Most recent frame as JPEG | From PSRAM; no SD access |
| `POST` | `/api/peek/fresh` | Queue a fresh capture for preview | Not saved, not logged |
| `GET` | `/api/config` | Current effective configuration | |
| `POST` | `/api/config` | Replace `config.json` | Rejected while capturing; validated set only |
| `POST` | `/api/stop` | Safe stop | `202 Accepted`; poll status for completion |
| `POST` | `/api/start` | Begin a new run | Only from an idle/finished state |

`/api/status` returns roughly:

```json
{
  "state": "capturing",
  "runId": "run_000003",
  "captureCount": 312,
  "savedCount": 47,
  "elapsedMs": 624000,
  "sdMounted": true,
  "motionRecent": [0.6, 1.2, 5.8, 0.4],
  "freeHeap": 210000
}
```

`motionRecent` is a short ring buffer of recent motion scores. It costs nothing — the values are already computed — and it drives the live "is anything moving?" meter in the UI, which doubles as a real tuning instrument for the outstanding motion-threshold work.

## Safe-stop sequence

The reason this project exists. Each step is already implemented except the unmount.

1. Phone `POST /api/stop`; handler enqueues `CMD_STOP`, returns `202`.
2. Main loop completes any in-flight capture — commands never land mid-write.
3. `logger.finish()`: promote the open dashboard chunk, write manifest and summary, mark the run `finished`, clear `active_run.txt`. *(existing, proven path)*
4. **`SD.end()`** — explicit unmount, forcing the final FAT flush. *(new; this is the step whose absence caused the 21 August corruption)*
5. State becomes `SAFE_TO_REMOVE`; the UI shows an unmistakable "safe to unplug" confirmation.
6. Operator disconnects power and removes the card.

**Honest limitation:** this does not make corruption impossible, because a child can still pull the cable at any moment. It makes the safe path available, easy, and more rewarding than the unsafe one. Atomic-write discipline and the hardware hold-up-capacitor question in the project brief both still stand.

## Phases and gates

Each gate must pass before the next phase begins. A failed gate returns to [ADR 0001](adr/0001-device-hosted-control-app.md) for revision rather than being worked around.

### Phase 1 — Serve a status page — DONE (21 August 2026)

SoftAP with WPA2, `WebServer` (Arduino-ESP32 core, no new dependency), UI from flash, `GET /api/status`. No SD interaction, no camera interaction, no commands.

Implemented in `include/control_server.h` / `src/control_server.cpp`, wired into `src/main.cpp`. Wi-Fi starts before any SD/camera/logger step, so the control app stays reachable and reports what failed even if the card is missing or a fatal setup error occurs (`state: "error"` with a message) — this was found and fixed during Phase 1 testing; the original ordering made Wi-Fi depend on the card, which defeated the point of having a status page.

**Gate: NOT fully met — reopened 21 August 2026.** Page load, live status, cadence, and heat all checked out. But a card audit after two live Wi-Fi test sessions (`run_000002`, `run_000003`, both post-reformat) showed **100% of motion checks triggered a save in both runs — zero `motion_not_detected` outcomes**, with scores clustering just above threshold (5.8–12) rather than the wide spread seen in the pre-Wi-Fi acceptance run (`run_000002` from the 21 August motion-mode fix, ~10% save rate, scores up to 89).

Two candidate explanations, and the comparison above does **not** distinguish them because both variables changed at once between the "before" and "after" runs:

1. **Environmental confound.** Testing moved from daylight to dark-outside-with-indoor-lighting between the two comparisons. Flickering indoor lighting (LED PWM dimming in particular) is a well-known false-trigger source for frame-differencing motion detectors and has nothing to do with Wi-Fi.
2. **Wi-Fi/radio interference.** SoftAP TX bursts draw meaningful current spikes; if that shows up as exposure micro-flicker, the motion score's whole-frame brightness correction may not fully cancel it.

**Resolved 21 August 2026: confirmed Wi-Fi, not lighting.** A same-scene control test (`run_000004`) with `control_server.begin()` disabled via a temporary `WIFI_CONTROL_DISABLED_FOR_TEST` build flag, everything else identical, showed 131 of 132 checks correctly returning `motion_not_detected`, scores maxing at 3.57 — well under threshold 5, and consistent in character with the original clean pre-Wi-Fi acceptance run. Same dark/indoor-lit scene as the two 100%-trigger runs; only Wi-Fi differed. This rules out the lighting-confound hypothesis and confirms **Wi-Fi/SoftAP radio activity measurably degrades motion-detection accuracy** on this hardware, most likely via power-rail noise showing up as exposure micro-flicker that the motion score's whole-frame brightness correction does not fully cancel.

**This gate cannot close as originally scoped.** Wi-Fi and motion-triggered capture cannot currently run together without breaking the motion detector. Before Phase 1 can be considered done, one of the following needs to happen:

- **Isolate the interference** — investigate power supply filtering/decoupling near the camera, reduce Wi-Fi TX power, enable modem sleep between HTTP polls, or move preview-frame timing away from TX bursts. Unproven whether any of this is sufficient without further hardware-level investigation.
- **Retune the motion detector to tolerate it** — widen the brightness-correction tolerance or threshold while Wi-Fi is active. Risks masking real motion along with the noise.
- **Don't run them together** — restrict Wi-Fi to a non-capturing review/setup window (device boots normally, capture-only; Wi-Fi and control only available in an explicit non-motion "review mode" between sessions). This changes the always-available "stop at any time" design goal and needs an owner decision if pursued.

Retain-every-frame sessions are unaffected by this finding, since they have no motion comparison to disturb. The safe-stop mechanism (Phase 2) itself is unaffected and remains validated independently — this finding is specific to motion-triggered capture running *concurrently* with Wi-Fi, not to the control app generally.

Not yet tested: iPhone/Safari. Not yet measured: current draw (hand-feel-warm check only so far).

### Phase 2 — Safe stop — BUILT, gate partially exercised (21 August 2026)

Implemented: a `volatile bool` flag set by the `POST /api/stop` handler and consumed only by the main loop between captures (no FreeRTOS queue needed — `WebServer::handleClient()` and capture already run on the same task, so a flag alone gives the same "only at safe points" guarantee the plan called for). `SdStorage::end()` added (`SD.end()`) and now called unconditionally from `finishSession()`, both on a phone-triggered stop and on the existing `max_session_seconds` timeout path, since the timeout path had the same unmount gap. New `safe_to_remove` status state drives the phone UI's confirmation screen.

**Gate:** exercised twice live (not yet the full 20 cycles) — both stops produced `state: "finished"` manifests (`run_000002`, `run_000003`), `py tools\audit_card.py` clean (730/730 images accounted for, only pre-existing warning was an orphaned `.tmp` from the earlier `run_000001` crash, predating this work), zero storage errors. Remaining before this gate is formally closed: run the rest of the 20-cycle count, and confirm behaviour when the phone disconnects/sleeps mid-stop (fire-and-forget from the client side, believed safe since the device acts on the request regardless of whether the response is received, but not yet deliberately tested).

*This phase is where the corruption risk is actually retired. Everything after it is convenience.* The UI's "Packing up…" wait (observed ~10s, dominated by dashboard-chunk promotion and unmount) has no real progress signal yet since the device can't serve HTTP while `finishSession()` blocks the loop — an indeterminate spinner was added for now; real incremental progress would need `finishSession()` broken into steps that yield back to `handleClient()`, not yet done.

**Known blocker carried from Phase 1:** motion-triggered capture cannot currently run at the same time as Wi-Fi (see Phase 1 above). Phase 2's safe-stop mechanism itself is unaffected by that finding and works correctly in both motion and retain-every-frame sessions; it's specifically motion *scoring accuracy* that breaks when Wi-Fi is active.

**Follow-up (22 August 2026): daylight retest, not yet a full control test.** A daylight session with Wi-Fi on (`run_000006`, 586 checks, safe-stopped via the phone) showed normal-looking motion discrimination — ~10% save rate, wide score spread 0.39–16.8 — unlike the two dark-scene 100%-trigger runs from the night before. This points toward the interaction being light/gain-dependent rather than a fixed effect of Wi-Fi, which would make it a more attackable problem. Not yet confirmed: there is no daylight run with Wi-Fi *off* to complete the comparison, so daylight-has-less-to-trigger-on hasn't been ruled out as an alternative explanation. Owner has accepted Phases 1–2 as complete for now regardless, treating the remaining controlled test as a nice-to-have rather than blocking further work.

### Phase 3 — Peek and live motion — BUILT (22 August 2026)

PSRAM double-buffered last frame, `GET /api/peek`, `motionRecent` in status. Implemented in the same files as Phases 1–2. The "fresh photo" queued command (forcing an out-of-band capture rather than showing the last one taken) was **not** built this pass — peek currently only ever shows the most recently *actually* captured frame, which in motion mode can go stale between motion events. Documented in the UI copy rather than solved.

Tested live: both peek and the motion meter work. One finding, not a blocker: the motion meter's updates are visibly uneven — a delay, then several bars appear to update at once. Root cause: `WebServer::handleClient()` and capture share one task, so the device can't respond to a status poll while it's mid-capture — and a real motion *save* (the moments the meter is most interesting) includes an SD write that can take several hundred ms, right when the client is most likely to be polling for a fresh value. The poll catches up afterward with several new ring-buffer entries at once. Mitigated for now with a CSS transition on the bar heights so a multi-step catch-up animates smoothly instead of snapping; the underlying cause (HTTP blocked during capture/SD-write) is unfixed and would need real concurrency to address properly — out of scope for this phase.

**Gate:** peeks during an active session cause no cadence disruption, no storage errors, and no false motion triggers — observed clean. Motion meter matches values later found in `captures.csv` — not yet cross-checked. "No cadence disruption" specifically needs re-confirming given the blocking behaviour just described; nothing observed so far suggests it affects capture timing itself, only HTTP responsiveness.

### Phase 4 — Configuration — DONE for `GET`/`POST /api/config` (22 August 2026)

`GET`/`POST /api/config` implemented and confirmed live on hardware, including surviving a real power cycle (saved setting via phone, restarted the board, new setting was in effect). `POST /api/start` (arm/idle state, starting a new run without a physical reboot) **deferred, not built** — see below.

Implementation note: the plan originally said to reject config writes "while capturing." On reflection that was overcautious and has been relaxed. `config.json` is read exactly once, at boot; nothing else touches it during a session, and the SD storage layer's atomic-write pattern already makes concurrent-ish writes safe. The actual constraint is simply **the card being mounted** — writes are accepted throughout a normal capturing session and rejected only once a safe stop has unmounted the card (`sd_mounted: false`), which matches the existing SD-dashboard settings tool's "takes effect after restart" model. The handler validates and queues; the main loop performs the actual `writeTextAtomic()` between captures, same pattern as the stop command.

The phone UI offers the same four fixed combinations as the SD-card dashboard's settings tool (1/2/30/60 s interval; high/low quality; 1/5/30/60 min or infinite duration; motion toggle), tucked into a collapsible "Grown-up helper" section so it doesn't clutter the child-facing screen.

**`POST /api/start` deferred, but the design is now settled (22 August 2026) and should be cheap to build next time.** Originally scoped as re-running the SD/camera/logger bring-up sequence at runtime from the main loop — rejected on reflection as needlessly risky: `AppConfig`, `SessionLogger` (which itself owns a `DashboardWriter` with its own chunk-tracking state), `CameraService`, the motion-baseline pair, the motion-history ring buffer, and several more globals in `main.cpp` would all need correctly resetting by hand, in a second code path that has never been exercised, duplicating logic that `setup()` already gets right.

**Simpler, safer alternative, implemented same day: `POST /api/start` just calls `ESP.restart()`** after flushing the HTTP response, when `state` is anything except `capturing`/`warming_up` (`409` while those, so an accidental tap can't interrupt a live session — the phone should hit Finish first). Reuses the exact boot sequence already proven for weeks instead of a fresh, untested one. Added a "Start another adventure" button to the safe screen, and fixed a real gap this exposed while building it: `poll()` had no path back to the main screen once the device restarted (it would sit on "safe to unplug" forever) — added an `awaitingRestart` flag so the first successful poll after the reboot returns the UI to the main screen automatically.

**Follow-up (22 August 2026, first live test): saving a setting had no reachable way to apply it.** `POST /api/start` existed but only "Start another adventure" on the post-finish safe screen could call it — there was no path from the settings panel itself, so a saved setting had nowhere to go without a physical power cycle. Fixed: a "Restart now to use this setting" button appears in the settings panel after a successful save. If the device is idle/finished, it calls `/api/start` directly. If a session is actively running, it first asks for confirmation (this ends the current session early), then chains `POST /api/stop` → wait for `safe_to_remove` → `POST /api/start` automatically, client-side — reusing the two already-proven endpoints rather than adding a new "restart while capturing" path in firmware. `handleStart()`'s own validation is unchanged and still rejects a raw restart attempt during `capturing`/`warming_up`.

Built and flashed without a phone to test against — logic reuses already-proven pieces (the stop/start endpoints, the existing `awaitingRestart` recovery path), but the live chained flow itself needs confirming on hardware.

**Bug found on first live test of the restart-now flow (22 August 2026): saved settings were not taking effect after restart.** `GET /api/config` after the reboot showed the old value, not the saved one. Found one real, concrete bug: `main.cpp`'s config-write consumption called `storage.writeTextAtomic("config.json", ...)` — missing the leading slash that `ConfigLoader::load()`'s read path (`"/config.json"`) and every other atomic write in the codebase uses. Fixed and reflashed.

**Confirmed fixed on retest (22 August 2026).** The missing leading slash genuinely was the bug — settings now correctly take effect via the "Restart now" software-restart path. Resolves the earlier open question: the ESP32 SD library does not silently normalize a relative path to root here, so this was a real correctness bug, not a red herring. Worth remembering as a general lesson for this codebase: `fs::FS` paths need the leading slash to match `SD.open()`'s behaviour, and it can fail in a way that's easy to miss (no crash, no fatal error — it silently writes to a location boot-time loading never reads).

**Gate: met, confirmed live.** Config writes round-trip via `GET /api/config`, survive the software-restart (`POST /api/start`) path, and take effect on the next boot as intended. Invalid combinations rejected with `400`; writes rejected with `409` once the card is unmounted. `POST /api/start` and the restart-now flow are built and confirmed working end to end.

### Phase 5 — Access and enclosure integration — FIRMWARE HALF BUILT (22 August 2026)

**Decision (22 August 2026, owner call): fixed, shared Wi-Fi credentials across every device, not per-device.** Originally built as MAC-derived per-device SSID/password; revised same day. Rationale: this ships in quantity to schools, the SD card's contents are not sensitive, and unique-per-device credentials add real manufacturing/support cost (a distinct QR sticker per unit) for no meaningful security benefit in this context. The password is kept — not for confidentiality, but so a teacher can control who joins the network. One shared QR design now works for the entire product line.

- **Network**: SSID `InsectCam`, password `antcamera` (reusing the original Phase 1 placeholder as the permanent value — already exercised through every phase's testing so far). Fixed constants in `control_server.cpp`, no longer derived from the MAC.
- **Known, accepted trade-off**: multiple kits running in the same room broadcast an identical network name. A phone may need to pick the right access point manually if more than one is nearby (they'll differ by signal strength/BSSID even with the same SSID, but iOS/Android don't always surface that clearly). Not mitigated; acceptable for now.
- **Captive-portal DNS redirect**: `DNSServer` (bundled with the Arduino-ESP32 core, no new dependency) answers every DNS query with the device's own IP, and any unrecognised HTTP path also lands on the control app (`server_.onNotFound`). This is what should make a phone's own connectivity-check request (`connectivitycheck.gstatic.com`, `captive.apple.com`) resolve back to the device and trigger an automatic captive-portal pop-up, instead of the phone reporting "no internet" and going no further.
- **QR payload logged at boot**: `WIFI:S:InsectCam;T:WPA;P:antcamera;;`, printed to serial alongside the existing SSID/IP diagnostic.
- **A real QR code has been generated** (`qrcode` Python library, error-correction level M, encoding the exact payload above) and sent to the owner to scan-test directly, ahead of any physical sticker.

**Confirmed working on Android (22 August 2026):** scanning the QR joined the network, and the captive-portal redirect worked — Android showed its standard "Sign in" notification, and tapping it opened the control app without anyone typing an IP address. Note this is Android's normal captive-portal behaviour (notification rather than an automatic browser pop-up); the goal of "never needs to know the IP" is met.

**iPhone/Safari: blocked, no device available.** The project owner does not have an iPhone, so this cannot be tested in-house. iOS handles captive portals differently from Android (it typically auto-opens a restricted mini-browser rather than posting a notification), and that mini-browser has known limitations — it is not full Safari, and can behave differently around JavaScript, `fetch`, and page lifecycle. **This is an untested platform, not a working one**, and needs either borrowed hardware or an external tester before any claim of iOS support. Until then, treat the browser matrix for the control app as Android-only.

**Not yet done, and not attempted without a phone/enclosure:**
- Printing the QR code onto the physical enclosure.
- Confirming the captive-portal auto-open behaviour actually fires on real Android and iPhone hardware — this varies a lot by OS/browser and is exactly the kind of thing that looks correct in code and still doesn't work in practice.
- The printed fallback-IP label for when captive-portal detection doesn't fire.

**Gate: half met.** The Android half is satisfied — QR scan to working control app, no IP address needed. The iPhone half is **blocked on hardware availability**, not on implementation, and must not be assumed to pass by analogy with Android. The physical sticker is also still outstanding.

### Phase 5 amendment: SSID made per-device again, QR-code joining dropped (17 September 2026)

The 22 August decision's accepted trade-off (identical network name across every kit in a room) turned out to matter once multiple units were actually running in the same room — the owner asked to fix it. Re-reads as a partial reversal, not a full one: **only the SSID changed, the password did not.**

- **SSID**: `InsectCam-` plus 3 hex digits, derived from `ESP.getEfuseMac()` (the chip's factory-programmed, permanently unique ID) at boot — `wifiSuffix()` in `control_server.cpp`. No per-unit setup-time bookkeeping: the same firmware image produces a correct, different suffix on every board automatically. 4096 possible suffixes, not collision-proof but ample headroom for how many kits are actually likely to share a room.
- **Password**: unchanged, still the fixed `antcamera` shared across every device. The 22 August rationale for a shared password (no real confidentiality need, teacher-gatekeeping only) was never actually about the SSID being shared too — those were bundled into one decision that didn't need to move together.
- **QR-code joining dropped, deliberately, not merely undone.** The 22 August reversal's real driver was the manufacturing/support cost of a *unique QR sticker per unit* once credentials stopped being shared — reintroducing that per-unit SSID uniqueness while trying to keep QR joining would have brought that exact cost straight back. Chose instead: a child joins by picking their own unit's name from the phone's normal Wi-Fi list (now meaningfully distinct per unit, unlike before), with the enclosure labelled at setup time. `tools/setup_device.py` reads the assigned SSID back over serial right after flashing (`report_wifi_name()`) and prints it clearly for exactly this purpose - no manual lookup, no guessing.
- The `docs/barcelona-demo-guide.html`/`-es.html` guides and `docs/setup-guide.md`/`docs/barcelona-demo.md` runbooks were updated to describe "find your unit's name in the Wi-Fi list" instead of "scan this QR code." `docs/assets/insectcam-wifi-qr.png` is no longer part of the instructed flow; left on disk rather than deleted, since it's still accurate historical evidence of the Phase 5 Android test.
- **Not yet tested live**: a real "two units in one room, confirm each phone can tell them apart and join the right one" run. The suffix derivation and the boot-time readback have each been verified independently (firmware compiles, `check_project.py` passes), but not yet the full two-device scenario together.

## Risks

| Risk | Severity | Mitigation |
| --- | --- | --- |
| Concurrent SD access corrupting the card | High | Command queue; main loop is sole SD owner; handlers never touch the card |
| Wi-Fi radio activity breaks motion detection (100% false-trigger rate, confirmed 21 Aug via same-scene control test) | High, confirmed | Not yet mitigated. See Phase 1 write-up for options: isolate the interference, retune detection tolerance, or don't run Wi-Fi and motion capture concurrently |
| Thermal build-up from an active radio in a sealed enclosure | Medium | Measure in Phase 1 before building further; consider modem sleep or reduced TX power |
| Phone drops the AP for having "no internet" | Medium | Captive portal; documented fallback IP; test on named devices |
| Peek buffer read during overwrite | Medium | Double buffer with atomic index swap |
| Fresh capture triggering false motion save | Medium | Mandatory re-baseline after any out-of-band capture |
| Wi-Fi work displacing the pilot critical path | Medium | Endurance test, browser matrix, and battery smoke test stay ahead of this track |
| Open AP allowing a stranger to stop a run | Low | WPA2 with per-device password |

## Open questions

- Should Wi-Fi be on for the whole session, or only for a window after boot? Always-on is required for stop-at-any-time to work, which argues for always-on unless thermal measurements say otherwise.
- Should the device auto-start capture on power-up (current behaviour, and what the brief's "power on and walk away" requires), or wait to be armed from the phone? Default should stay auto-start, with manual arm as an option.
- Does the peek frame need downscaling before entering the PSRAM buffer, or is a full QXGA JPEG acceptable over Wi-Fi to a phone?

## Related

- [ADR 0001](adr/0001-device-hosted-control-app.md) — the decision and its scope boundary
- [hardware-validation.md](hardware-validation.md) — the corruption incident that motivated this
- [project-brief.md](project-brief.md) — must be updated to record the scope change
- [next-session.md](next-session.md) — current priorities; this track runs alongside, not instead of, pilot acceptance

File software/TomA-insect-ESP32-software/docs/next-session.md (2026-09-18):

# Next session checklist

## Priority order for when the owner is back (2 September 2026 hand-off)

Several remote sessions (27 August - 2 September) covered a lot of parallel ground; this orders it by what actually needs *physical presence or the owner's own action* versus what's genuinely done or still doable remotely. Full detail for every item is in its own section below - this is a map, not a replacement.

1. **Barcelona demo.** See [barcelona-demo.md](barcelona-demo.md) for the working runbook and the new printable [guide](barcelona-demo-guide.html) (+ [Spanish](barcelona-demo-guide-es.html), both with PDFs and real assembly/screenshot photos now, not placeholders). Still needs: a real end-to-end rehearsal on the travelling hardware, physical assembly instructions from the enclosure subgroup (not in this repo's scope - though the guide now has real photos of the actual build sequence, supplied by the owner), and the Wi-Fi QR code printed onto the enclosure (`docs/assets/insectcam-wifi-qr.png`, already made). The board was flashed and the card updated+cleaned on 14 September 2026 (see below) - it is currently in a real, ready-to-demo state, not just "code complete."
2. **White-balance: closed as "materially better, not solved."** Daylight re-check done 2 September 2026 (`run_000082`): a real, visible improvement over every pre-seed trial (much weaker cast than the green/purple/magenta seen before), but a mild residual purple/mauve tint remains, mostly in shadow - not a clean neutral pass. See "White-balance fix" below for the full trail and an open idea (try a longer post-seed pump) for whoever wants to push this further. Not currently blocking anything - a product call on whether this residual cast matters enough to chase further.
3. **Get the Device Guard IT exception** for `C:\Users\tomaug\.platformio\packages\tool-cmake\bin\cmake.exe`, or decide between that / WSL2 / building on the collaborator's machine. Blocks all further progress on the on-device ant edge model ([ADR 0002](adr/0002-on-device-ant-edge-model.md)) - see that section below. A draft request email was prepared 31 August 2026 (see chat), not yet sent.
4. **Finish the one-hour pilot acceptance's physical-only items**: `audit_card.py`/`camera_trial_report.py` with the card actually in a reader; battery pack/cable, enclosure, and temperature observations; a live-insect (not printed-photo) image-quality review. See "First: one-hour QXGA pilot acceptance" below - this remains the critical path to calling the pilot done, ahead of every other track here.
5. **Browser-model evidence and motion-trigger acceptance** both need a physical session with the card in a reader / deliberate movement in front of the camera - see their sections below. Note a newly-found issue if motion-trigger mode is picked up again: it reinitialises the sensor on every single retained capture, which the white-balance investigation now shows resets AWB gain each time too - motion mode's colour behaviour has not been checked with this in mind.
6. Lower urgency, no blocker: direct-write config and USB-MSC feasibility tracks (bottom of this file), device-control-app iPhone testing (needs borrowed hardware) - also relevant to the Barcelona demo's phone step.

**Per-device Wi-Fi names, 17 September 2026 - reopens and partially reverses the 22 August 2026 shared-SSID decision.** The owner ran into the exact trade-off that decision accepted (identical network name across every kit in the same room) and asked to fix it. `ControlServer::begin()` now derives the SSID from the chip's own factory-unique ID (`ESP.getEfuseMac()`, last 3 hex digits) - `InsectCam-A3F` style, different on every board automatically, no per-unit setup step. The password stays shared (`antcamera`, unchanged) - only the SSID moved. Deliberately **not** a full reversal: QR-code joining is dropped rather than brought back, since a unique-per-unit QR sticker was the actual cost the original decision was avoiding, and reintroducing per-device SSIDs while keeping QR would have brought that straight back. A child now finds their unit by name in the phone's own Wi-Fi list instead. `tools/setup_device.py` reads the assigned name back over serial right after flashing (`report_wifi_name()`, reusing the DTR/RTS-clearing fix from `dev_bridge_client.py` so opening the port to read it doesn't reboot the board) and prints it clearly enough to label the enclosure with. Updated everywhere the old fixed `InsectCam` name was instructed as current behaviour: `docs/setup-guide.md`, `docs/barcelona-demo.md`, both guide HTML files (+regenerated PDFs), and the decision records themselves (`docs/adr/0001-device-hosted-control-app.md`, `docs/device-control-app-plan.md` - appended, not rewritten, matching how the original 22 August decision is recorded). `tests/check_project.py` pins the suffix derivation, the readback function, and that the guides no longer instruct QR-scanning.

**Tested live on a second, genuinely different board (chip `E8:F6:0A:8B:B2:C8`) and a real bug turned up immediately**: `report_wifi_name()`'s first version opened the serial port and read for the just-flashed board's *first* post-flash boot, and lost every time - the "control app ready" line prints within a second or two of esptool's own hard-reset, and by the time `subprocess.run` returns, the module imports, and the port opens, that line has already gone by unread. Fixed by rewriting it to reuse `dev_bridge_client.py`'s already-proven `Bridge` class (same DTR/RTS-safe open) and deliberately issuing `DEV REBOOT` only once already connected and listening, so the diagnostic line is guaranteed to print after the read loop has started rather than racing it. Reproduced the fix twice on the same board (`InsectCam-6E8` both times, confirming the suffix is stable across reflashes as designed) via both the standalone function and the real `py tools\setup_device.py --flash-only` path. Still outstanding: a real two-units-in-one-room join-the-right-one rehearsal with a phone.

**Spanish language support added and deployed to real hardware, 14 September 2026 - still needs a native speaker's review of the Spanish text before Barcelona.** The owner asked to run the whole kit in Spanish as well as English. Built across three areas, each with its own mechanism (see the approved plan for the full reasoning):
- **The Barcelona guide**: a full parallel `docs/barcelona-demo-guide-es.html` (+ its own PDF), cross-linked with the English version. Both later got their placeholder photos replaced with the owner's real assembly/screenshot photos.
- **The dashboard** (`dashboard.html`, `demo.html`, `dashboard.js`, `analysis.js`, `settings.js`, `card-access.js`): new `dashboard/i18n.js` - a locale *registry* (`LOCALES` + `translations`), not a hardcoded EN/ES toggle, so a third language later is one more entry, not a rebuild. Composed/pluralized strings (session counts, durations) are per-locale functions so each language's own grammar lives in its own function body. A flag+code dropdown picker replaces what used to be (per the owner) a similar picker in an earlier iteration. `tools/prepare_sd.py` and `tools/install_dashboard_demo.py` were both missing `i18n.js` from their file lists at first - caught and fixed (a card without it would fail to load the dashboard at all); `tests/check_project.py` pins this specifically so it can't regress silently, the same way the INSECT-AI label gap was pinned after being found.
- **The phone control app** (`src/control_server.cpp`): same registry pattern, inlined into the existing single PROGMEM HTML string (one copy of markup, not two) since firmware flash has no separate file to load from. The fixed C++ error responses (`handleStart`, `handleConfigWrite`) carry an additive `errorCode` alongside their existing English `error` text, so the client can show a translated message without any API-consumer breaking. Boot-time `fatal_error` diagnostics generally still show their raw English/technical suffix (an accepted gap, not silently left) - **except** the two board-vs-card codes added the same day (see below), which now go through the same `errorCode` mechanism and are fully translated.

**Real-hardware verification, same day**: firmware flashed, dashboard files (including `i18n.js`) deployed to the actual card over the serial dev-bridge (byte-size-verified), and the AI/settings modals plus the control app's settings panel confirmed rendering correctly in both languages via headless-browser renders beforehand. `check_project.py` (7/7) and a clean `platformio run` build (25.7% flash) both pass. **Still not done**: native-speaker review of the Spanish text - the one deliberately-deferred item.

**Board-vs-SD-card diagnostic, 14 September 2026.** Mid-flash, the board stopped mounting its SD card entirely (`SD mount failed on GPIO21 at every supported clock speed`) - turned out to be the two physical halves (XIAO main board and the Sense expansion board carrying the camera + SD slot) not being fully seated together, not a bad card. The failure text was identical either way, because `storage.begin()` has no way to see the camera and `setup()` returns before ever reaching `camera.begin()` if storage fails first. Fixed with a new dev-bridge `PROBE` command (`src/dev_bridge.cpp`) that initialises the camera alone, independent of storage - verified live in both states (`camera=fail` with the boards separated, `camera=ok` once reconnected, SD still failing identically both times). The same distinction now also reaches the phone app: a storage-mount failure probes the camera too and sets a stable `errorCode` (`expansion_board_disconnected` / `sd_card_not_found`) alongside the existing raw diagnostic, translated the same way as every other app error. Also added while debugging this remotely: a `WIPE CONFIRM` dev-bridge command (no recursive delete existed before; per-file `RM` would have meant thousands of round-trips) - used the same session to clear the real card (1,785 files, 26 directories) once it finally mounted. See [dev-bridge.md](dev-bridge.md) for the full command reference and reasoning.

**AI models now ship by default, 13 September 2026 - a recorded risk acceptance, not a silent one.** Investigating why the live card's AI panel had no models led to the owner asking to ship them in the standard setup and commit them to GitHub. FlatBug's weight-redistribution review (`docs/model-card.md`) was, and still is, genuinely incomplete - the owner explicitly chose to accept that risk rather than complete the review first; AntAI-Beta carries no such risk, being the project's own model. Implementation: canonical copies now live at `dashboard/ai/` (four model/runtime files, `LICENSE-onnxruntime.txt` fetched verbatim from the real Microsoft repo rather than reconstructed from memory, and a provenance `README.md`), `tools/prepare_sd.py` installs them on every fresh card, and `tools/install_ai_pack.py` was simplified to pull from the same canonical location (for adding the pack to an older card without a full re-prepare). The decision itself is recorded in `docs/model-card.md` under "Redistribution decision, 13 September 2026", not just in this changelog, since that is the document that originally flagged the gate as open. `tests/check_project.py` pins both the decision record and the files' presence.

While investigating why the models were missing, two real performance bugs surfaced on the live card (28,717 capture records, only 1,036 surviving images after reconciliation) and were fixed the same session:
- **Movie and AI panels slow to open/use** (owner reports, 13 September 2026): `card.fileFor()`'s scan fallback made every "file genuinely no longer on the card" lookup scan the entire file index - measured at 86,032,548 wasted iterations across 27,681 such lookups on this card alone. Fixed by dropping the scan from that hot path (a capture's path always matches one of two indexed forms already built at load time); `fileByName`'s own by-name scan is untouched since its rare, small-scale callers (config.json, model files) genuinely need it. The movie panel separately computed its capture list three times per status update; now once. **Then the owner asked the sharper question directly: why walk capture records at all just to list session names, when the folder picker already handed over the file list?** It shouldn't, and now doesn't - `card.sessionCounts()` (new, in `card-access.js`) derives session names and picture counts straight from the file paths (`images/<run-id>/...`), so listing and browsing sessions is O(files on the card) and touches `data.captures` not at all. Matching a session's records to their files - the one thing that genuinely needs the capture log - now happens only for the one session actually in use, only when the user presses Start looking or Make movie. Verified end-to-end with an instrumented headless run: opening either panel, switching AI model choice, and browsing between two sessions (including a synthetic 28,717-record one) all measured **zero** calls into the capture-resolving function; pressing Start looking measured exactly 28,717, scoped correctly to the session selected at that moment.
- **Switching AI model choices felt laggy** (owner report, 13 September 2026): the radio-button change handler called `loadCard()` → `loadModel()` immediately, fetching the model and starting the WebAssembly runtime on every switch, before the user asked to run anything. Model loading is now deferred to the "Start looking" click; switching choices only updates the label. Verified by counting calls into the loading path from outside: zero on every switch, exactly the expected count when Start is actually pressed.

**Dashboard review, 12 September 2026:** the owner reviewed the dashboard and reported six issues. All six are fixed and verified; see "Dashboard review fixes" below for what each was, what changed, and the one that needed a design judgement (issue 6). Awaiting the owner's re-review.

**SD card was never actually named `INSECT-AI`, 14 September 2026 (found while drafting Barcelona demo materials).** The dashboard's folder picker has told users to "choose the INSECT-AI drive" since it was written (`dashboard.html`, `dashboard.js`, `analysis.js`, `settings.js` all say so), but nothing in `prepare_sd.py`/`setup_device.py` ever set that as the drive's actual volume label - the owner noticed their own prepared card wasn't named that and correctly guessed the setup step was simply missing, not that they'd done something wrong. Fixed: `prepare_card()` now calls a new `set_volume_label()` (Windows only, via `SetVolumeLabelW`) at the end of card preparation, guarded so a failed rename never blocks the rest of preparation - it just prints manual rename instructions instead. macOS is not automated (would need a `diskutil` call, not yet written/tested); documented as a one-time manual rename in `setup-guide.md`'s Part 4.2 and its Troubleshooting section, and in `operations.md`. `tests/check_project.py` pins the constant and the call. **Not yet done:** the owner's own already-prepared physical card still needs either a manual rename or a re-run of `prepare_sd.py` against it - this fix only affects cards prepared from now on.

The large-`CAT` dev-bridge bug is an open finding but **not blocking anything** - see its section for what a fix would need. The storage-remaining metric is no longer an open dashboard item: the tile was replaced (see below), though the underlying firmware `SD.totalBytes()` bug it was waiting on is still real and still unfixed.

## Remote/unattended working arrangement (27 August 2026)

The owner is away for a while, with the board left powered over USB and the SD card inside it (not in a reader). A serial development bridge (`include/dev_bridge.h`, `src/dev_bridge.cpp`, `tools/dev_bridge_client.py`) was built and verified live for exactly this: inspecting and changing the card without physical access. Full protocol, safety model, and the two real bugs found while building it (a silent reboot-on-connect, and silently dropped bytes on bulk writes) are in [dev-bridge.md](dev-bridge.md) - read that before using it.

In short: `py tools\dev_bridge_client.py --port COM4 stop` before any file command, `mount` to remount afterward, `reboot` to apply a config change or start a fresh run. File commands are refused outright while a session is capturing, so there is no way to race a write by mistake. For remote audit specifically, use `runs` (all run states in one call) and `audit <run_id>` (per-run image/shard/timing stats computed on-device, ~2 minutes) rather than pulling `raw/captures.csv` directly - that reliably fails past a certain size, see dev-bridge.md.

Remember commits made in this repo are **not** automatically visible on GitHub — see [CLAUDE.md](../CLAUDE.md) for the subtree publish step, which needs to be run separately from `C:\k4k\kit-for-kids`.

## On-device ant edge model: blocked on Device Guard, not a dead end (30 August 2026)

New scope, [ADR 0002](adr/0002-on-device-ant-edge-model.md): trying a collaborator's ESPDet-Pico ant model on-device. `spikes/edge-ant-model/` found the *approach* looks viable (mixed `arduino, espidf` framework resolves and downloads cleanly for this exact board once the project's space-laden path is worked around - see the spike's own README for that fix), but is currently **blocked by this machine's Device Guard policy** refusing to run the downloaded `cmake.exe` - a different binary than the already-known `pio.exe` launcher-stub block, needing its own exception. Three options recorded, none yet actioned: an IT exception for `C:\Users\tomaug\.platformio\packages\tool-cmake\bin\cmake.exe`, setting up WSL2 (would likely sidestep this whole class of restriction, but needs setup - no distro currently installed), or building on a different machine (the collaborator has already solved this exact toolchain problem somewhere) and transferring only the compiled firmware for flashing here. Resume by trying whichever of those three is easiest to arrange, then continuing the spike from where it left off (ESP-DL itself hasn't been added yet - only the framework-mixing step was attempted).

Status at hand-off (18 August 2026): image-quality trials are concluded. The settled pilot setting is QXGA (2048?1536), JPEG quality 12, 1 FPS, with a maximum 3,600-second session. The firmware and `config.example.json` enforce this normal `pilot` setting; the mounted deployment card must be prepared with `py tools\configure_camera_trial.py <card-root> --install-pilot-default`. Earlier trial captures are retained as evidence and must not be deleted automatically.

## First: one-hour QXGA pilot acceptance

**Largely done, 28 August 2026, both runs over the dev bridge while unattended** - see the findings in [hardware-validation.md](hardware-validation.md). Two independent one-hour runs (dark `run_000041`, daylight `run_000050`): both clean self-finishes, no reboot, no storage error, no corruption, but **both short of 3,600** (3,589 and 3,585) - confirmed lighting-independent, since the daylight run's normal-sized JPEGs didn't close the gap or even reduce the worst-case interval. Image-quality review is **done** (daylight run): soft focus (fixed-focus/DOF characteristic, not subject-specific), acceptable exposure, and a real new finding - a colour cast at session start that clears within ~30 minutes (auto-white-balance settling). Still needed:

1. ~~Confirm the card uses the pilot default~~ done. ~~Daylight repeat~~ done - see above; it changed the conclusion rather than confirming the original theory, which is itself useful.
2. Mount the card and run `py tools\audit_card.py <card-root>` and `py tools\camera_trial_report.py <card-root>` - still not yet run against either card (both need a mounted local path; the dev-bridge `audit`/`runs` commands approximate their checks remotely but can't check manifest/chunk consistency or orphaned temp files the way the real scripts do). Do this properly next time a card is in a reader.
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

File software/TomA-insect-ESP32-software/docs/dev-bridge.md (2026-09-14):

# Serial development bridge

A line-based command channel over the same USB serial link used for flashing, so the SD card can be inspected and changed while it stays inside the board. Built on 27 August 2026 specifically for unattended/remote development: normally a card change means physically moving the card to a reader, which is not possible without someone present.

Deliberately not USB mass storage or Wi-Fi. Serial is the one channel already proven reliable for this board, and reconfiguring the USB stack for MSC risks losing the ability to flash — exactly the wrong failure mode to introduce right before working unattended.

## Safety model

**The main loop is the sole owner of the SD card, same as everywhere else in this firmware.** `DevBridge::poll()` is called once per `loop()` iteration, gated on `ready && !finished` exactly mirroring the condition that gates `captureOnce()` — so a file command can never execute in the same cycle a capture write could happen.
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

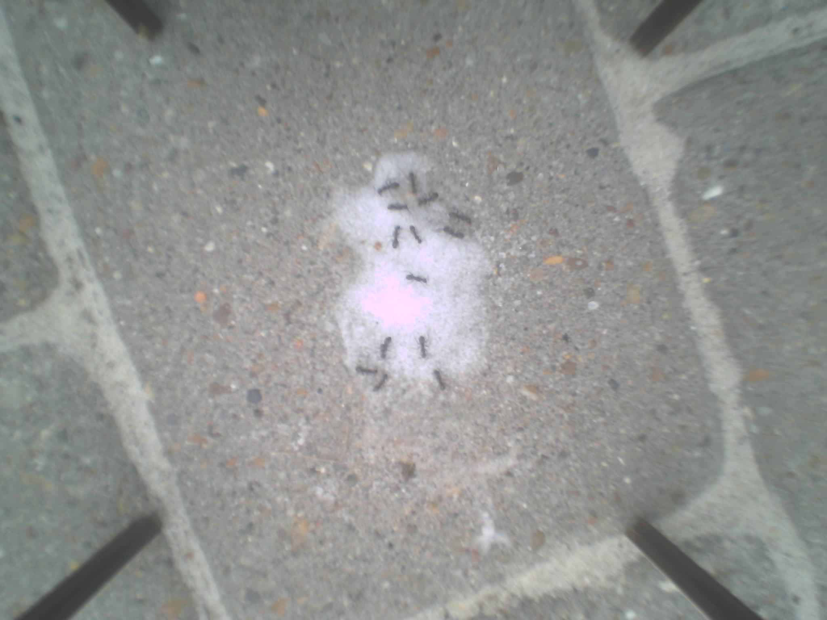
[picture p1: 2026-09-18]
software/TomA-insect-ESP32-software/dashboard/images/demo_run_000001/shard_0001/run_000008_img_2019.jpg

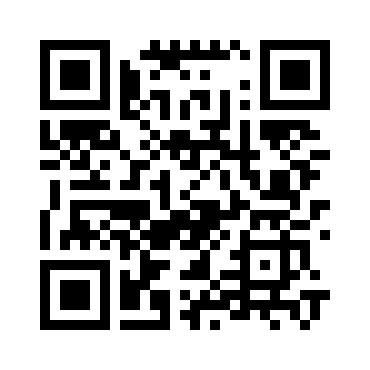
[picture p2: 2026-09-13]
software/TomA-insect-ESP32-software/docs/assets/insectcam-wifi-qr.png

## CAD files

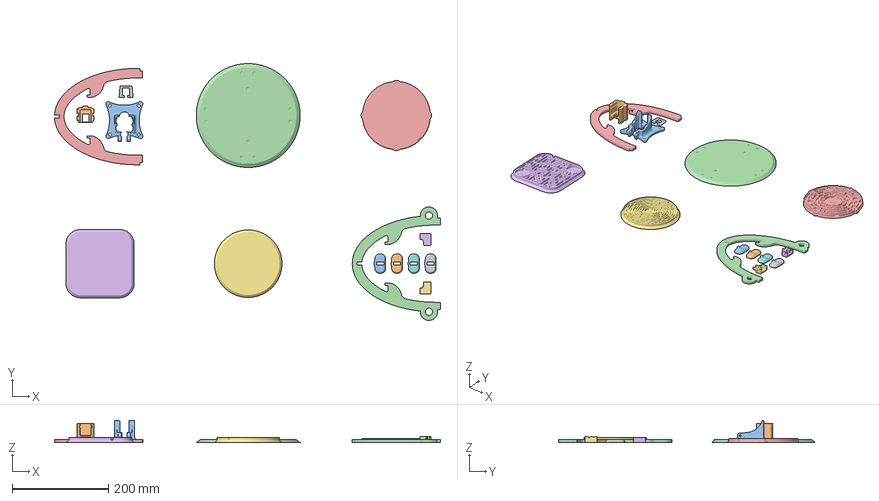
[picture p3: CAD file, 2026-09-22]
3D Printed Files/KitForKids-BambuLAB A1 settings.3mf
800.3 x 532.6 x 46.0 mm
Cam Enclosure fix.stl
Rack.stl
Rack&Pinion support.stl
Base.stl
Maze1.stl
Maze2.stl
Maze3.stl
Column Magnetic connector.stl x 4
Top Column.stl
Bottom Column (1).stl
Camera Enclosure - v2 - Part 1.stl
Camera Enclosure - v2 - Part 2.stl

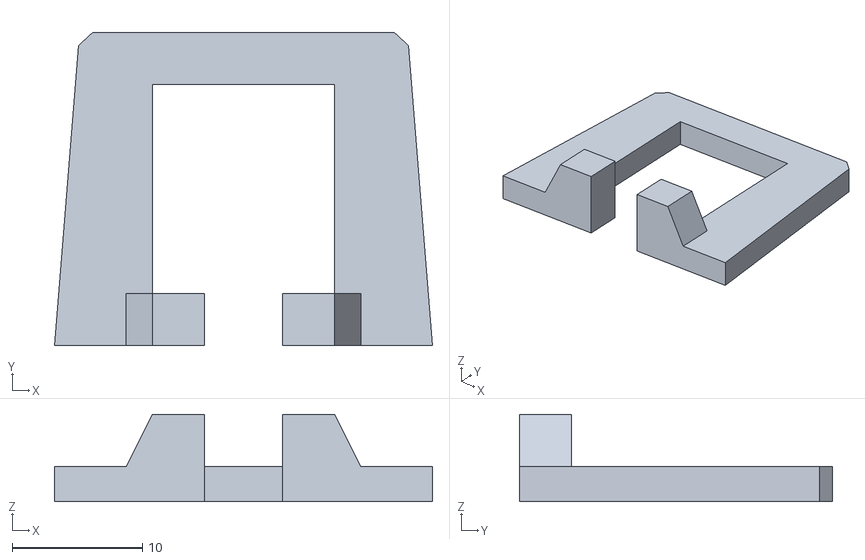
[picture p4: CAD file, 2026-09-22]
3D Printed Files/STL/Cam Enclosure fix.stl
29.0 x 24.0 x 6.70

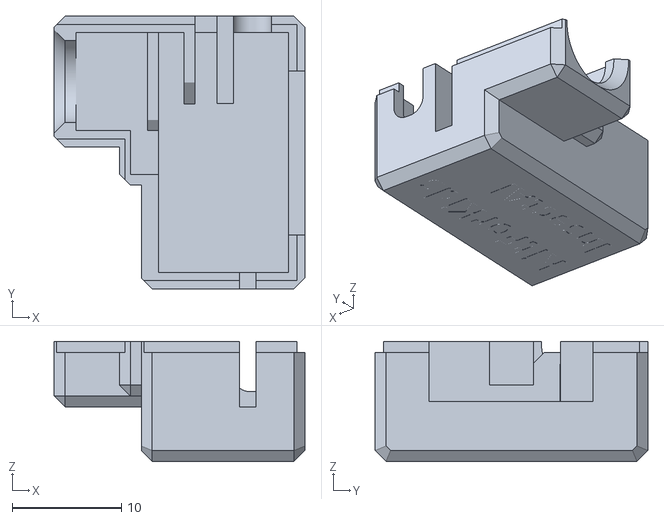
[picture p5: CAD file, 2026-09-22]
3D Printed Files/STL/Camera Enclosure - v2 - Part 1.stl
23.0 x 25.0 x 11.0

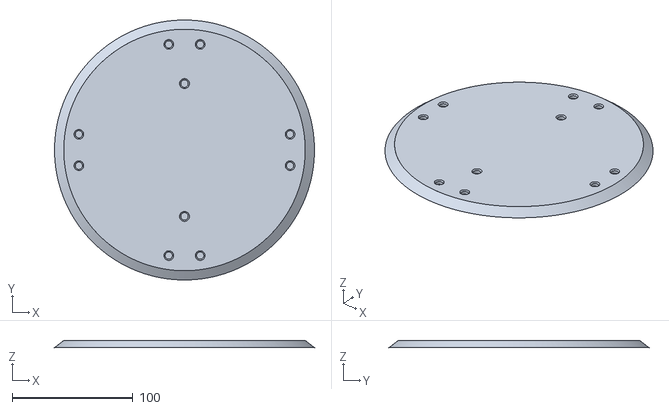
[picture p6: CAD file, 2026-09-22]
3D Printed Files/STL/Base.stl
215.4 x 215.4 x 6.00

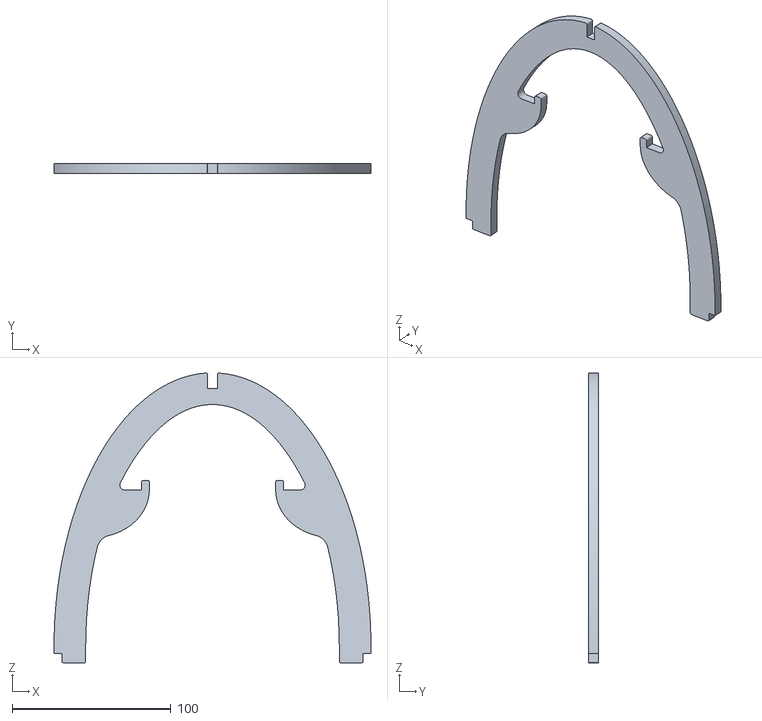
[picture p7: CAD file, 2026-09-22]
3D Printed Files/STL/Bottom Column.stl
200.0 x 6.00 x 182.9

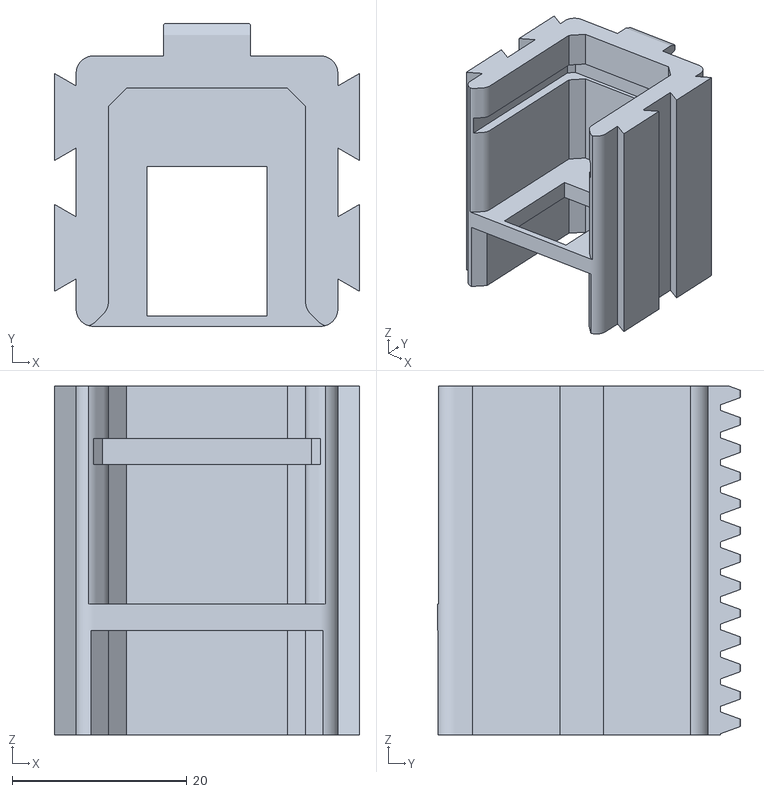
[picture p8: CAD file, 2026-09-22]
3D Printed Files/STL/Rack.stl
35.0 x 34.7 x 40.0

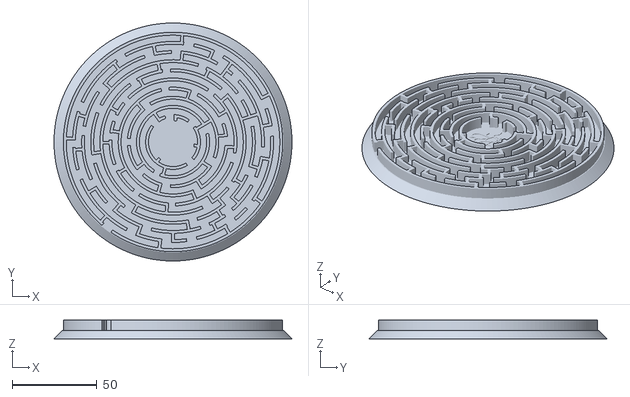
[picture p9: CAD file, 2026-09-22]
3D Printed Files/STL/Maze3.stl
140.0 x 140.0 x 11.0

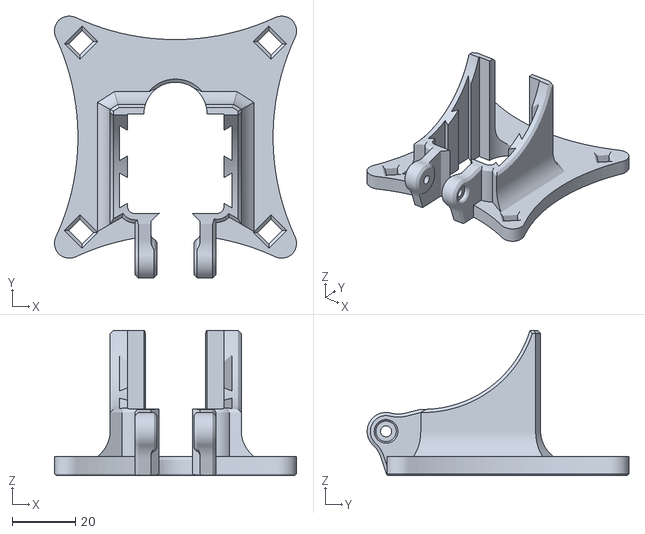
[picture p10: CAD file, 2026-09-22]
3D Printed Files/STL/Rack&Pinion support.stl
76.7 x 83.0 x 46.0

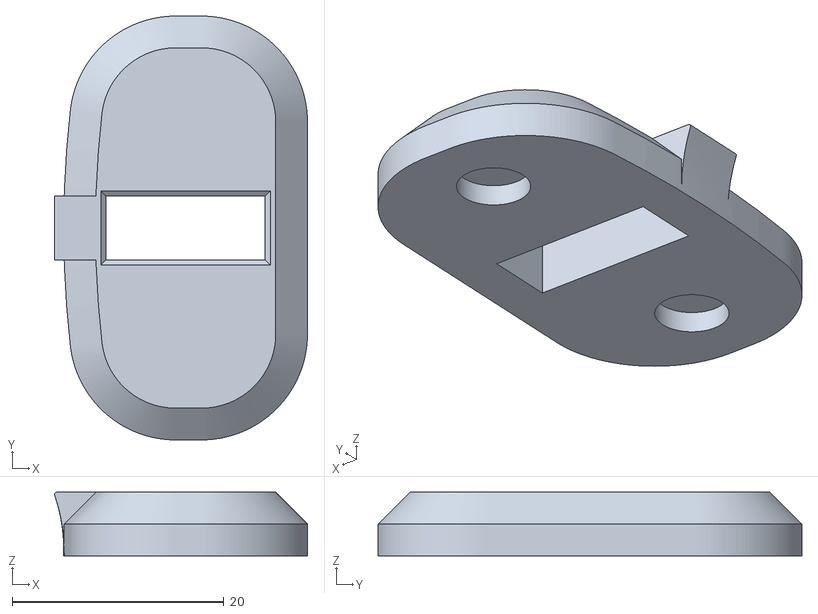
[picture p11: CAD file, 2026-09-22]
3D Printed Files/STL/Column Magnetic connector.stl
23.9 x 40.0 x 6.00

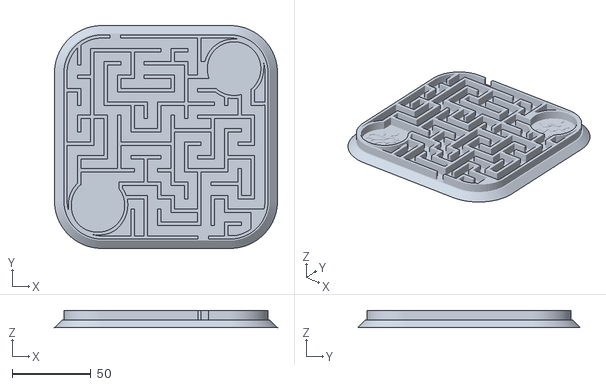
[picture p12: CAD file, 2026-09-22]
3D Printed Files/STL/Maze2.stl
141.5 x 141.4 x 11.0

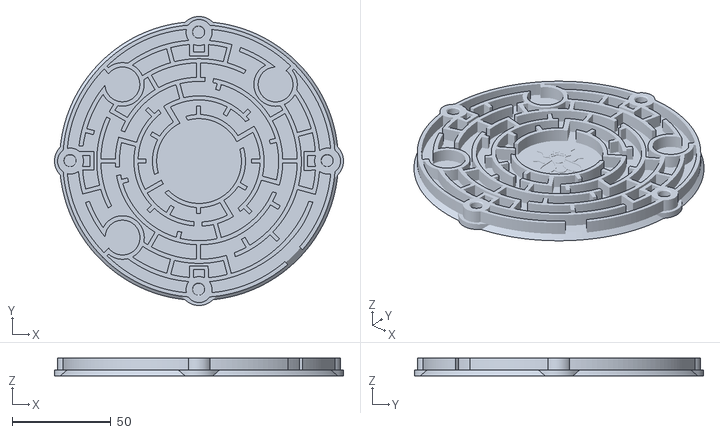
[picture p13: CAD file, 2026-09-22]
3D Printed Files/STL/Maze1.stl
146.1 x 146.1 x 9.00

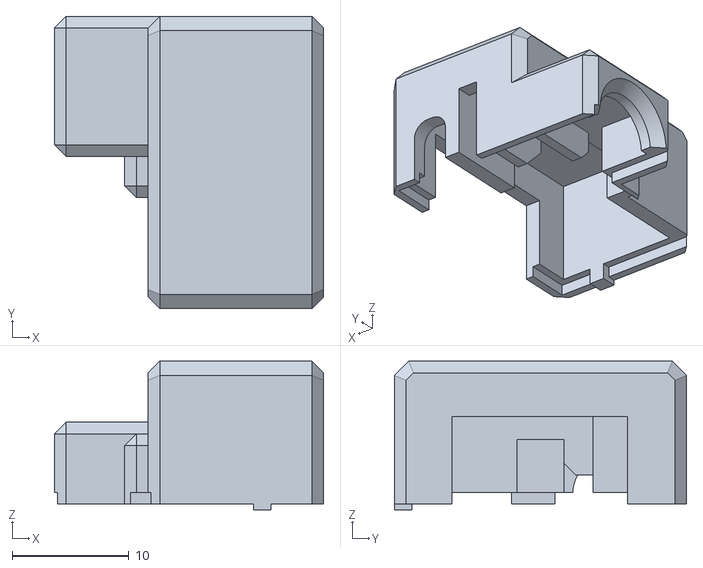
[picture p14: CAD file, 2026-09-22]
3D Printed Files/STL/Camera Enclosure - v2 - Part 2.stl
23.0 x 25.0 x 12.7

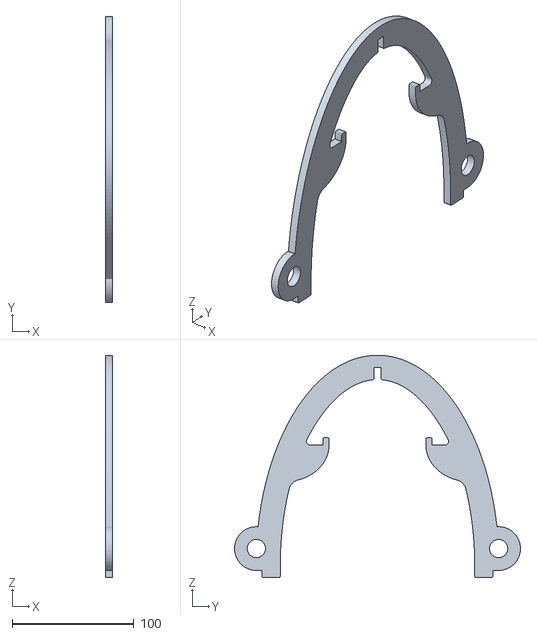
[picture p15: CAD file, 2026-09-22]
3D Printed Files/STL/Top Column.stl
6.00 x 235.3 x 183.0

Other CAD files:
3D Printed Files/STL/Camera Enclosure - Part 3.stl

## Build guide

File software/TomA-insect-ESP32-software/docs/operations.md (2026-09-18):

# Operation guide

## Set up a new device

Run `py tools\setup_device.py` on a development computer with the board plugged
in and a formatted FAT32 card in a reader. It flashes the firmware, then runs the
card preparation below. Use `--flash-only` or `--skip-flash --card <root>` to do
one half; `--port`, `--card` and `--yes` make it non-interactive. See the
[setup guide](setup-guide.md).

## Prepare a card

1. Format a supported microSD card as FAT32. Formatting removes existing data.
2. On a development computer, run `py tools\prepare_sd.py <card-root>` (or `py tools\setup_device.py --skip-flash --card <card-root>`). On Windows this also names the drive `INSECT-AI`, matching what the dashboard's folder picker tells users to choose; on macOS, rename it yourself (Finder → select the drive → press Return) since that step is not yet automated there.
3. Inspect `config.json`. Normal `pilot` mode is fixed to QXGA (2048?1536), JPEG quality 12, 1 FPS, and sessions no longer than 3,600 seconds. Install that normal setting with `py tools\configure_camera_trial.py <card-root> --install-pilot-default`. The separate, short `quality_trial` mode is retained only as historical/diagnostic tooling; see [camera-quality-trial.md](camera-quality-trial.md).
4. The preparation tool updates static dashboard files but preserves the runtime-generated `manifest.js` and `summary.js` when they already exist.
5. For a transferred card, run `py tools\audit_card.py <card-root>` before changing or deleting anything.
6. Save the audit output with a read-only backup or card image.
7. Safely eject the card and insert it into the powered-off camera.

## Collect a session

1. Connect the battery power cable.
2. The unit is configured to capture and retain every QXGA/JPEG-quality-12 frame at a 1-FPS target for up to one hour (3,600 images). A production model has not yet been installed, so all inference outcomes are `model_unavailable`. The one-hour QXGA cadence/endurance acceptance run remains outstanding.
3. Disconnect the battery cable to stop the device. This is the normal stop method; never remove the microSD card while powered.
4. The firmware flushes each image and raw CSV row as it is captured. Dashboard records are written in bounded closed chunks plus `data/captures_current.js`; the current chunk is loaded by the dashboard so a normal power removal remains visible.

## Review and delete data

1. Remove the card only after power is disconnected.
2. Insert it into a normal computer and open `dashboard.html` in Chrome, Edge, Firefox, or Safari while offline.
3. The dashboard shows the total number of loaded captures, while the recent frames and image gallery initially show at most ten items. Use `Show all frames` or `Show all images` to expand the lists; the buttons then change to `Show fewer frames` or `Show fewer images`.
4. To try experimental browser AI in Chrome or Edge: as of 18 September 2026 both FlatBug and AntAI - Test ship automatically with `py tools\prepare_sd.py <card-root>` (Part 3); for an older card prepared before that date, add them with `py tools\install_ai_pack.py <card-root>`. Select **Find insects with AI**, choose one option: **AntAI - Test** (ant-only), **FlatBug - Quick look** (faster) or **FlatBug - Look closely** (slower, 12 tiles). Select **Load camera card**, choose the clearly labelled **INSECT-AI** drive, then choose the desired saved session and press **Start looking**. The dashboard analyses only that session; it never mixes image records from separate experiments. The same selected card can be reused by the movie maker until the tab closes. Pictures are analysed locally, one at a time, with live possible-insect clues and pause/stop controls. These are predictions, not validated identifications, and nothing is uploaded or written back to the card.

5. Select **Make my insect movie** to create a raw-picture time-lapse. If the card is not already loaded, select **Load camera card** and choose the **INSECT-AI** drive. The movie maker uses only image files that still remain on the card, defaults to the newest available session, and lets an adult choose another available session. In current Chrome or Edge, it creates a finalized 1024x768 MP4 download locally at exactly 60 pictures per second. The encoder assigns each picture its intended timestamp, so image-reading time does not stretch the movie; the dashboard shows progress and provides a cancel control. Nothing is uploaded, changed on the card, or automatically written back to it. AI-overlay movies are not yet implemented.
6. Select an image to open it in the page modal; use the `x` control, Escape, or the backdrop to close it.
7. For a safe rehearsal demonstration (real reference ant photos, fabricated run/timing data), run `py tools\install_dashboard_demo.py <card-root>`, then open `<card-root>\demo\demo.html` - it opens already loaded (images and AI models are embedded at install time), no folder to choose, so you can go straight to **Start looking**. This is visibly separate from real captures. The demo also includes its own practice copies of **Make my insect movie** and **Camera settings** for risk-free rehearsal; the settings tool writes only to the demo folder's own `config.json`, never to a real camera card.
8. Use the computer's file manager, not the dashboard, to delete data when starting a new experiment. Do not delete files during collection.
9. Preserve `/raw/captures.csv` when analysis matters: it is the authoritative record.

## Recovery

- Missing or corrupt `config.json`: restore `config.example.json` as `config.json`.
- A missing or empty `manifest.js` means only the current open chunk can be loaded. Do not overwrite a runtime manifest with the starter dashboard file; `py tools\prepare_sd.py` now preserves it automatically.
- On the next boot, the firmware promotes the previous open chunk and marks its run `interrupted_power_removed` before starting a new run.
- Run `py tools\audit_card.py <card-root>` before cleanup. The audit is read-only and reports missing CSV-referenced images, temporary files, unlisted chunks, stale run states, and raw/dashboard count drift.
- Camera/SD fault: record the serial diagnostic, firmware version, card type, and run identifier before retrying.

## Experimental direct dashboard configuration

The dashboard now includes a **Camera settings** tool for use only while the board is switched off and its card is mounted. In current Chrome or Edge, choose **Camera settings**, grant the browser explicit write permission to the top camera-card folder, choose each safe setting, and confirm the write. The choices are: one picture every 1 second, 2 seconds, 30 seconds, or 1 minute; high-quality QXGA or low-quality VGA; a 1-minute, 5-minute, 30-minute, one-hour, or infinite session; and an experimental **Save pictures only when something moves** option. Infinite means collection continues until power is disconnected or the card fills. When the modal opens, it reads the card-root `config.json`, displays the exact current setting, and aligns the offered controls with it when it is one of the supported safe combinations. After saving, it confirms the same setting has been written. The default remains to retain every image. With the motion option enabled, the camera waits five seconds after power-on, always saves its first image, then checks each scheduled low-resolution preview and saves a configured-quality JPEG only where its local change score reaches 5. It still logs every check, so the dashboard count can be larger than the image count. The tool replaces only the card-root `config.json`; the configuration takes effect after the board is restarted and firmware still validates it.

For an older card whose `captures.csv` predates motion mode, run `py tools\migrate_capture_schema.py <card-root>` before collecting a score-tuning run. The tool preserves every row, adds blank motion columns to rows whose scores were never collected, and leaves a timestamped backup on the card.

The existing image/AI picker remains read-only. Browser file objects cannot be upgraded to write access, so the settings tool deliberately asks once for a writable card-folder handle. If the browser declines or does not support that permission, it must leave the card unchanged. Mobile-browser support is not yet accepted; it is an explicit next feasibility test.

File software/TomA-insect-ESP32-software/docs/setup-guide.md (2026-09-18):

# Setting up the insect camera: a step-by-step guide

This guide takes you from a bare camera board to a working insect camera with pictures on your screen. It assumes you are comfortable using a computer — installing programs, finding files, plugging things in — but **not** that you have ever programmed a microcontroller or used a command line before. Where a command line is unavoidable, every command is given in full for you to copy.

Read [operations.md](operations.md) once you are set up; it is the shorter day-to-day reference. This guide is the one-time setup.

> **Estimated time:** about 45 minutes the first time, most of it waiting for software to install. Setting up a *second* camera afterwards takes about 5 minutes.

---

## Before you start: what you need

**Hardware**

| Item | Notes |
| --- | --- |
| Seeed Studio XIAO ESP32S3 **Sense** | The "Sense" version is essential — it is the one with the camera connector and microSD slot |
| OV3660 camera module | Usually supplied with the board |
| microSD card, 32 GB or smaller | Must be 32 GB or under. Larger cards use a format the camera cannot read |
| USB-C cable | Must be a **data** cable, not charge-only. See troubleshooting if the board is not detected |
| USB battery pack | Any standard phone power bank |
| The enclosure | Not covered here; this guide is about the software |

**Computer**

- Windows 10/11 or macOS. This guide shows Windows paths; on macOS the commands are the same but paths use `/` instead of `\`.
- About 1 GB of free disk space.
- An internet connection **for setup only**. Once set up, the camera and dashboard work entirely offline.

**Optional**

- An Android phone, if you want to use the camera's own control app (see Part 6). *iPhones are not yet supported — see the note in that section.*

---

## Part 1 — Install the software (one time only)

You need two things: **Python** and **PlatformIO**. Python runs the small helper tools; PlatformIO puts the firmware onto the camera board.

### 1.1 Install Python

1. Go to [python.org/downloads](https://www.python.org/downloads/) and download the latest Windows installer.
2. Run it. **Tick "Add python.exe to PATH"** on the first screen — this matters, and it is easy to miss.
3. Click *Install Now* and wait.

To check it worked, open a terminal (press <kbd>Win</kbd>+<kbd>R</kbd>, type `powershell`, press Enter) and type:

```powershell
py --version
```

You should see something like `Python 3.13.1`. If you get an error, Python is not on your PATH — reinstall and make sure that box is ticked.

### 1.2 Install PlatformIO

PlatformIO is the tool that compiles the firmware and sends it to the board. In the same terminal you just used, run:

```powershell
py -m pip install platformio
```

This downloads a few tens of megabytes and takes a minute or two. The much larger ESP32 compiler toolchain (several hundred megabytes) is fetched automatically the first time you build, in Part 3.

To check it worked:

```powershell
py -m platformio --version
```

You should see `PlatformIO Core, version 6.x.x`.

> **Why install with `py -m pip` and run with `py -m platformio`?** Both forms pin PlatformIO to the *same* Python you checked in step 1.1, so the two always agree. Installing PlatformIO another way — in particular through *only* the "PlatformIO IDE" Visual Studio Code extension — puts it somewhere `py -m platformio` cannot see, and every command in this guide then fails with `No module named platformio`. If that happens, run the `py -m pip install platformio` command above to fix it. A bare `pio` is also avoided throughout: some managed or school-issued computers block it while allowing the longer form.

> **Prefer buttons to typing?** You can additionally install [Visual Studio Code](https://code.visualstudio.com/) and its `PlatformIO IDE` extension (Extensions icon in the left sidebar → search `PlatformIO IDE` → **Install**; 5–10 minutes, longer on a slow connection) for a graphical interface. This guide still uses the command line, because the commands are identical on every computer and easy to copy. The `py -m pip install platformio` step above is still needed for those commands even if you install the extension.

### 1.3 USB drivers

On Windows 10/11 and macOS, the XIAO board normally works with no driver installation at all. If the board is not detected later, see [Troubleshooting](#troubleshooting).

---

## Part 2 — Get the project code

The camera software lives inside the wider Kit-for-Kids project, in the folder `software/TomA-insect-ESP32-software`. You download the whole project, then work inside that one folder.

**Option A — download a ZIP (simplest, recommended)**

1. Go to [github.com/InsectAI-COST-Action/kit-for-kids](https://github.com/InsectAI-COST-Action/kit-for-kids).
2. Click the green **Code** button, then **Download ZIP**.
3. Unzip it somewhere memorable, e.g. `Documents\kit-for-kids`.

**Option B — use Git (better if you want updates later)**

Git does not come with Windows. Install it first from [git-scm.com/download/win](https://git-scm.com/download/win), accepting the default options, then in a terminal:

```powershell
git clone https://github.com/InsectAI-COST-Action/kit-for-kids
```

Either way, from now on **all commands are run from inside the camera-software folder**, not the top of the download. To get there in the terminal:

```powershell
cd "C:\Users\YourName\Documents\kit-for-kids\software\TomA-insect-ESP32-software"
```

You are in the right place if you can see files named `platformio.ini` and `config.example.json`:

```powershell
dir
```

> **Tip:** in File Explorer, navigate to that folder, then right-click while holding <kbd>Shift</kbd> and choose *"Open PowerShell window here"* to skip typing the path.

---

## Parts 3 and 4 the fast way — one command

Once Parts 1 and 2 are done, a single script does everything device-specific: it
builds and uploads the firmware, then installs the dashboard, folders and default
settings on the memory card.

1. Attach the camera module, plug the board in with a **data** USB-C cable.
2. Put the **FAT32-formatted** memory card (32 GB or smaller — format it first, see [4.1](#41-format-the-card)) into your computer's card reader.
3. Run:

   ```powershell
   py tools\setup_device.py
   ```

   It finds the board, asks you to confirm before flashing, then asks for the
   card's drive letter (e.g. `E:\`). That is the whole setup. It also prints this
   board's own Wi-Fi network name once flashing finishes — worth noting down to
   label the enclosure with, since it is different for every board (see Part 6).

To script it with no questions, or to do only one half:

```powershell
py tools\setup_device.py --port COM5 --card E:\ --yes   # both, unattended
py tools\setup_device.py --flash-only                   # firmware only
py tools\setup_device.py --skip-flash --card E:\         # card only
```

The card step never overwrites existing pictures, `config.json`, or a card's
runtime data, so it is safe to re-run. When it finishes, jump to
[Part 4.3](#43-eject-safely) to eject the card, then [Part 5](#part-5--run-a-capture-session).

The rest of Parts 3 and 4 below is the same work done by hand, step by step, if
you would rather see each piece or the script hits a problem.

---

## Part 3 — Put the firmware on the camera board

"Firmware" is the program that runs on the camera itself. You only need to do this once per board, or when updating to a newer version.

### 3.1 Connect the board

1. Attach the camera module to the board if it is not already fitted.
2. Plug the board into your computer with the USB-C cable.

### 3.2 Find which port it is on

```powershell
py -m platformio device list
```

You are looking for a line mentioning a COM port, e.g. `COM4` (on macOS, something like `/dev/cu.usbmodem1101`). Note it down. If nothing appears, see [Troubleshooting](#troubleshooting).

### 3.3 Flash it

Replace `COM4` with your port:

```powershell
py -m platformio run -e xiao_esp32s3 -t upload --upload-port COM4
```

The first time, this downloads the ESP32 compiler toolchain (several hundred megabytes) and can take 5–15 minutes depending on your connection, then a few more minutes to compile. Later runs take under a minute. You want to see:

```
Hash of data verified.
Leaving...
Hard resetting via RTS pin...
========================= [SUCCESS] =========================
```

The board restarts automatically and is now an insect camera.

Each board picks its own Wi-Fi network name automatically (`InsectCam-` plus 3 characters unique to that board — see Part 6). `py tools\setup_device.py` (below) reads this back and prints it for you right after flashing; flashing directly with `platformio run -t upload` as above does not, so open a serial monitor afterwards if you want to see it immediately — or just check once you reach Part 6.

---

## Part 4 — Prepare the memory card

### 4.1 Format the card

The card must be **FAT32**. Cards of 32 GB or less are usually FAT32 already, but formatting fresh is safest.

1. Put the card in your computer's card reader.
2. In File Explorer, right-click the drive → **Format**.
3. Set *File system* to **FAT32**. Leave everything else alone.
4. Click **Start**.

> ⚠️ **Formatting erases everything on the card.** Check you have the right drive.

### 4.2 Install the dashboard files

The card carries its own picture-viewing software, so it works on any computer with no installation. Replace `D:\` with your card's drive letter:

```powershell
py tools\prepare_sd.py D:\
```

This copies the dashboard, creates the folders the camera needs, and installs a default settings file. It deliberately **does not** overwrite existing pictures or settings, so it is safe to re-run on a card that already has data. On Windows it also names the drive **INSECT-AI**, so it's easy to spot later in the dashboard's folder picker — see Part 8. On macOS, that renaming step is not yet automated: rename the drive yourself in Finder (select it, press Return, type `INSECT-AI`).

### 4.3 Eject safely

Use *Safely Remove Hardware* (or drag to Trash on macOS) before pulling the card out. Then put the card into the camera board's slot.

---

## Part 5 — Run a capture session

1. **Check the camera is switched off** (nothing plugged in).
2. **Insert the memory card.** Never insert or remove the card while the camera has power.
3. **Connect the battery pack.** The camera starts on its own.
4. It waits 5 seconds for the camera sensor to settle, then begins taking pictures.
5. By default it takes **one picture per second at high quality, for up to one hour**, then stops on its own.

### Stopping safely

**This matters more than anything else in this guide.**

The safest way to stop is from the phone app (Part 6): tap **Finish my adventure**, wait for **"Safe to unplug now"**, then disconnect the battery.

If you are not using the phone app, either let the session run to its natural end, or disconnect the battery between pictures.

> ⚠️ **Why this matters.** The memory card can be damaged if power is cut while it is writing. We have seen this happen once during development: a card became unreadable and a whole session was lost. The firmware protects individual pictures carefully, but the card's own filing system is outside its control. The "Finish" button closes everything down properly first, which removes the risk. Always prefer it where you can.

---

## Part 6 — Use the phone control app (optional, Android)

The camera makes its own small Wi-Fi network so you can check on it, take a peek through its eyes, change settings, and — most usefully — stop it safely.

### Connecting

1. On your phone, open Wi-Fi settings and look for a network starting with **`InsectCam-`** — each board has its own name (3 hex digits after the dash, derived from the board's own chip ID), printed to the serial log during setup (Part 3) and worth labelling on the enclosure so it doesn't need looking up again. This matters once more than one kit is running nearby: each one's name is different, so there's no need to guess which access point belongs to which board.
2. Password: **`antcamera`** — the same for every board; only the network name is per-device.
3. Your phone will warn you there is no internet on this network. **This is correct** — you are connected directly to the camera, which has no internet by design. Choose to stay connected.
4. Your phone should offer a **"Sign in"** notification. Tap it and the camera's page opens.
5. If nothing appears, open a browser and go to **`192.168.4.1`**.

### What you can do

| | |
| --- | --- |
| **See progress** | How many pictures taken, how long it has been running |
| **Take a peek** | Shows the most recent picture the camera took |
| **Is anything moving?** | A live bar chart, when movement-triggered mode is on |
| **Camera settings** | Under *"Grown-up helper"* — change how often pictures are taken, quality, and how long to run. Save, then tap **Restart now** to apply |
| **Finish my adventure** | Stops safely and tells you when it is safe to unplug |

> **📱 iPhone users:** the control app has only been tested on Android. iPhones handle these camera-created networks differently and it may not work correctly. This is untested, not known-broken — but please do not rely on it until someone has confirmed it. Everything else in this guide works the same on any computer.

---

## Part 7 — Look at the pictures

1. **Stop the camera safely** (Part 5) and disconnect the battery.
2. Remove the memory card and put it in your computer.
3. Open the card in File Explorer and **double-click `dashboard.html`**.

That is all — no installation, no internet needed. It opens in your normal browser.

You will see how many pictures were taken, a gallery you can click through, and:

- **Make my insect movie** — turns the pictures into a fast time-lapse video you can save and share.
- **Motion watch** — a chart of when the camera detected movement (only appears if that mode was used).
- **Camera settings** — change settings for next time, from the computer instead of the phone.
- **Adult details** — a searchable table of every frame, tucked out of the way.

> **Browsers:** tested in Chrome and Edge. Firefox and Safari should work for viewing pictures but have not been formally checked yet. The movie maker and AI features specifically need Chrome or Edge.

### Starting a fresh experiment

Delete the `images`, `raw`, `data`, and `system` folders using File Explorer, then run `py tools\prepare_sd.py D:\` again. There is deliberately no delete button in the dashboard — deleting data should be a considered act, not one click.

---

## Part 8 — The AI helper (experimental)

The dashboard can look through pictures for possible insects, entirely on your own computer. Nothing is uploaded.

As of 13 September 2026 the AI models ship as part of the normal repository and are installed automatically by `py tools\prepare_sd.py D:\` in Part 3 — there is no separate download or step. If you are adding this to an older card that was prepared before that date, run:

```powershell
py tools\install_ai_pack.py D:\
```

In the dashboard, choose **Find insects with AI**, pick a mode, select the card folder when asked, and press **Start looking** — the chosen model loads at that point, not before.

> **Please read this before showing results to children.** These are **possible-insect guesses**, not identifications. The models are experimental, trained on very little data, and get things wrong in both directions — missing real insects and flagging things that are not insects. They cannot tell you a species. Treat every result as a prompt to go and look more closely, which is a good scientific habit anyway.

---

## Troubleshooting

**The board does not appear in `device list`**
- Try a different USB-C cable. Many cables charge only and carry no data — this is the most common cause by far.
- Try a different USB port, ideally directly on the computer rather than through a hub.
- Put the board into its flashing mode manually: hold the **BOOT** button, tap **RESET**, release BOOT. Then try again.

**`py -m platformio` fails with `No module named platformio`**
- PlatformIO is not installed in the Python that `py` runs. Run `py -m pip install platformio` (Part 1.2). This happens most often when only the PlatformIO VS Code extension was installed — it keeps a private copy the command line cannot see.

**`pio` is not recognised**
- Use `py -m platformio` instead, as shown throughout this guide.

**Flashing fails with "port is busy"**
- Close anything else using the port — a serial monitor, Arduino IDE, another terminal.
- Unplug and replug the board.

**The camera does not take any pictures**
- Check the card is inserted, formatted FAT32, and 32 GB or smaller.
- Check `config.json` exists on the card. If missing, re-run `py tools\prepare_sd.py D:\`.
- Connect to the phone app: if something failed at startup, it will say so in plain language.

**The card will not open on the computer / files look wrong**
- This can happen if power was lost mid-write. Run the read-only check first, which changes nothing:
  ```powershell
  py tools\audit_card.py D:\
  ```
- Do not reformat until you have asked for help — recovery may be possible.

**`dashboard.html` opens but shows no pictures**
- Confirm there are files in the card's `images` folder.
- Confirm you opened the file from the *card* rather than a copy of the project folder.

**Movement-triggered mode saves every single picture**
- Known issue when the phone Wi-Fi is active at the same time: the radio interferes with movement detection. Either use movement mode without the phone app connected, or use normal every-picture mode. Being investigated.

**The card isn't named `INSECT-AI` in the folder picker**
- `py tools\prepare_sd.py` names it automatically on Windows; if the card was prepared before this was added, or on macOS (not yet automated there), re-run `py tools\prepare_sd.py D:\` on Windows, or rename it yourself: File Explorer → right-click the drive → Rename (Windows), or Finder → select the drive → press Return (macOS).

---

## Quick reference

```powershell
# Flash the board AND prepare its card, one command (asks what it needs)
py tools\setup_device.py

# Flash firmware only (replace COM4)
py -m platformio run -e xiao_esp32s3 -t upload --upload-port COM4

# Prepare a card only (replace D:\)
py tools\prepare_sd.py D:\

# Check a card is healthy (read-only, safe)
py tools\audit_card.py D:\

# Add AI models to an older card (new cards get them automatically, see Part 3)
py tools\install_ai_pack.py D:\

# Try the demo without a real camera
py tools\install_dashboard_demo.py D:\
```

| | |
| --- | --- |
| Wi-Fi network | `InsectCam-` + this board's own 3-digit label |
| Wi-Fi password | `antcamera` |
| Camera page | `192.168.4.1` |
| Default settings | 1 picture/second, high quality, 1 hour maximum |

---

## What is still being worked on

Being straight with you about the current state, so nothing surprises you:

- **The full one-hour session has not yet been formally verified end to end.** Shorter sessions are well tested. If you run a full hour, we would genuinely like to hear how it went.
- **iPhone support for the phone app is untested.**
- **Movement-triggered mode is experimental** and currently conflicts with the phone Wi-Fi (see troubleshooting).
- **The AI models are experimental** and not included in the download.

Everyday use — set up, capture, view pictures, make a movie — is well tested and reliable.

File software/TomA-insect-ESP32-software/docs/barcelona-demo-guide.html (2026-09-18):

🐞 🐜 🦋 🐝 🪲

# Bug Camera Day!

Today you are going to run a real insect camera, catch its pictures, and let a computer try to spot the bugs in them — all by yourselves.

A step-by-step guide for pupils and teachers · InsectAI Kit-for-Kids

🇬🇧 English · 🇪🇸 Español

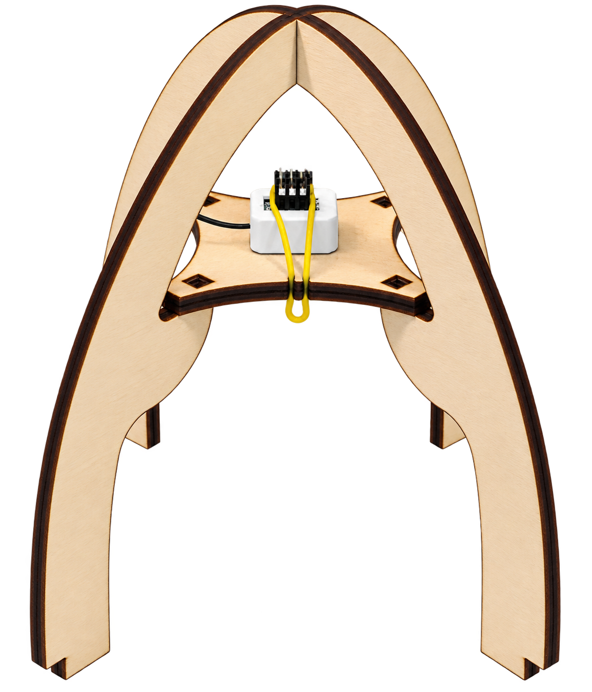
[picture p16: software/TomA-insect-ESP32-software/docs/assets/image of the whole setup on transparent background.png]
The finished insect camera, fully assembled


## What you'll need

- A camera, SD card and Wi-Fi antenna
- The camera enclosure (white)
- The camera stage - made of three pieces of wood, two arches and one 4 pointed star piece
- An elastic band
- The little picture of ants that goes underneath the camera
- The battery pack
- A USB-C cable, to connect the battery pack to the camera
- A phone — an Android phone works best for today
- A laptop or computer to look at the pictures afterwards

## Words to know

AI (Artificial Intelligence)

A computer program that has learned what insects tend to look like, and makes a best guess about where one might be in a photo. It can make mistakes — it's guessing, not certain!

SD card

The small memory card inside the camera that stores every photo it takes.

QR code

A special square pattern your phone's camera can read instead of you typing anything in.

Wi-Fi

How your phone talks to the camera without any wires, so you can peek at its photos while it's working.

Notes for the teacher / facilitator

- Always wait for 🏁 Finish my adventure to confirm before removing the card — this is what safely saves the photos.
- Never remove the SD card while the camera is still powered on.
- Each camera has its own Wi-Fi name (InsectCam- plus a short label), so several cameras can run in the same room without clashing — check every camera is labelled with its name before the day starts.

## Build your camera!

1

### Connect the antenna and slot in the memory card

If the antenna and SD card are not already connected, plug the little Wi-Fi antenna onto the camera board, and slide the memory card into its slot. This is what the camera will use to talk to your phone and to save every picture it takes.

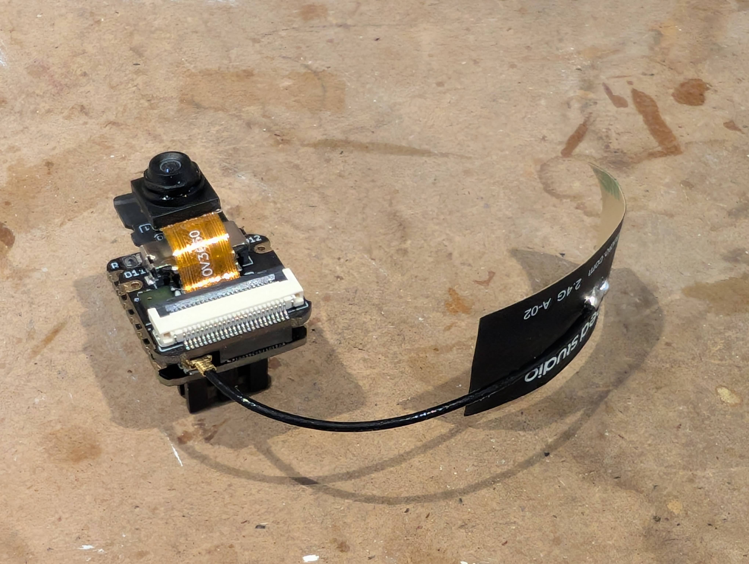
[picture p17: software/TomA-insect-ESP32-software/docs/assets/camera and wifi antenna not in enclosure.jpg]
The camera board and Wi-Fi antenna before assembly


2

### Close it into its case

If the camera board is not already in the case, tuck it carefully into the white case so the lens looks out through the hole, then close the case.

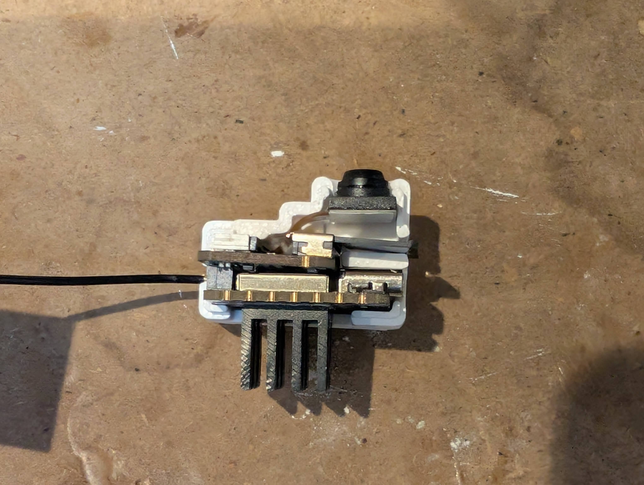
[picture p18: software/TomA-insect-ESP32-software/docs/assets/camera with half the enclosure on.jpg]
The camera board fitted into the first half of the case


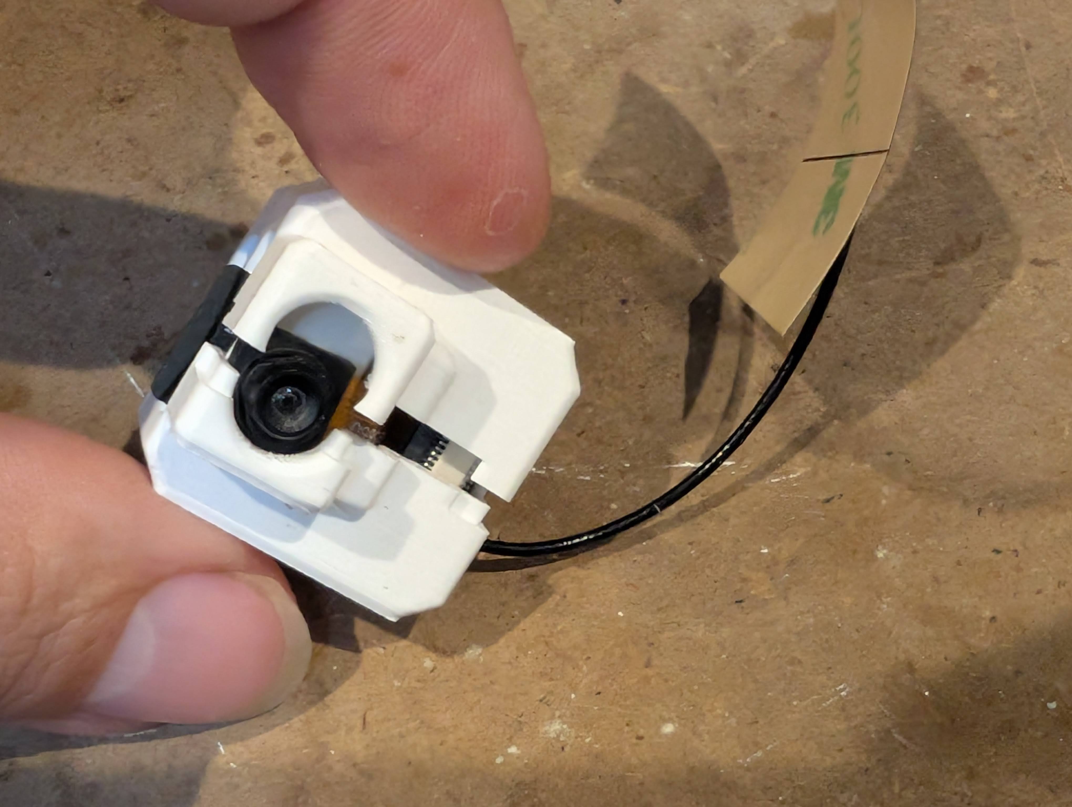
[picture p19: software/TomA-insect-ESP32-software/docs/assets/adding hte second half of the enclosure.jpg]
Adding the second half of the case on top


3

### Fix it to the star platform

Sit the camera into the wooden star-shaped platform so that the camera goes into the hole in the center. Stretch the elastic band across it, using the hooks on each side so that the elastic band goes around the heatsink, pressing the camera into the hole in the center.

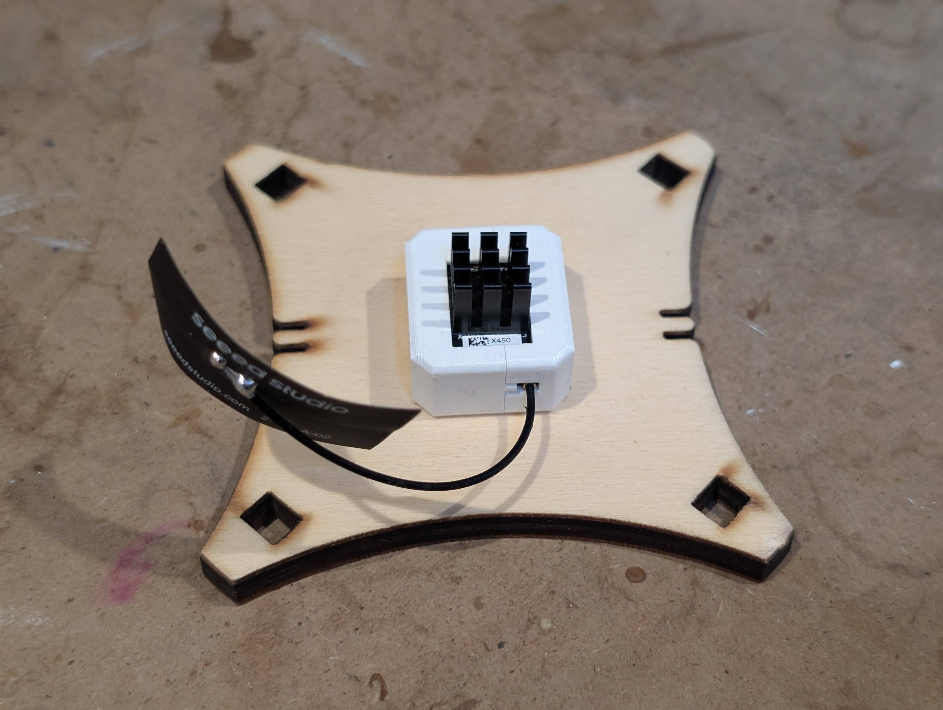
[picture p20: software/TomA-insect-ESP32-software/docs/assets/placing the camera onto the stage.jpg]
Placing the case onto the star-shaped platform


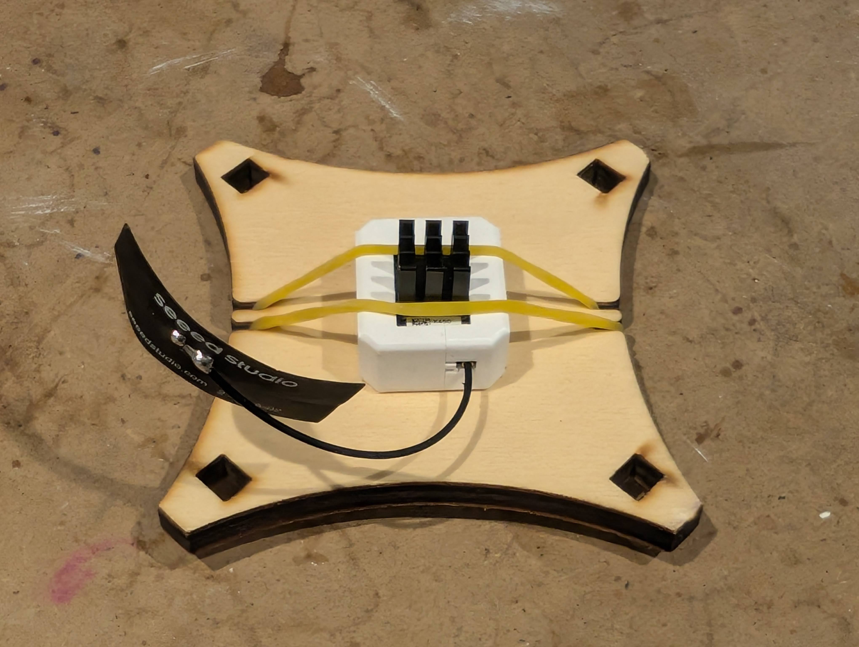
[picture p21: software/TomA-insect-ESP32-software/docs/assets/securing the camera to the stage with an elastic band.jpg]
Securing the case to the platform with the elastic band


4

### Build the arch

Slot the two curved wooden arch pieces together at the top, so they stand up together on their four legs.

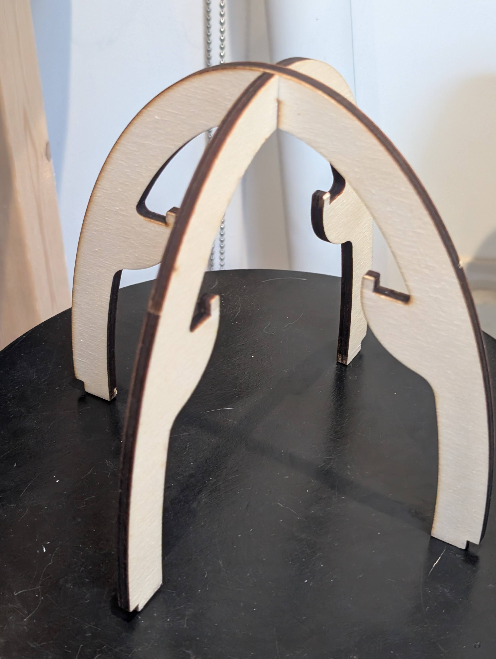
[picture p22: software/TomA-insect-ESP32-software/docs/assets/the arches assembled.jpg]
The two arch pieces slotted together


5

### Slide the platform into the arch

Raise the star platform — with the camera strapped to it — up into arches. Once at the top of the arches rotate it and lower it onto the notches pressing it gently into place.

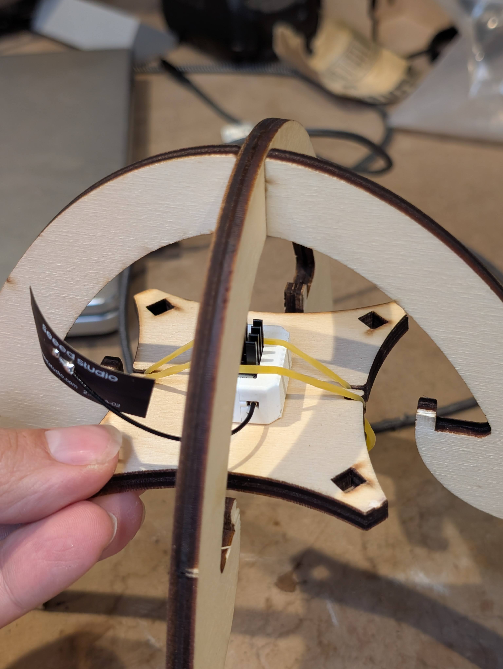
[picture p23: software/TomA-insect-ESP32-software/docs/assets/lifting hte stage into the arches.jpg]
Lowering the platform into the arch


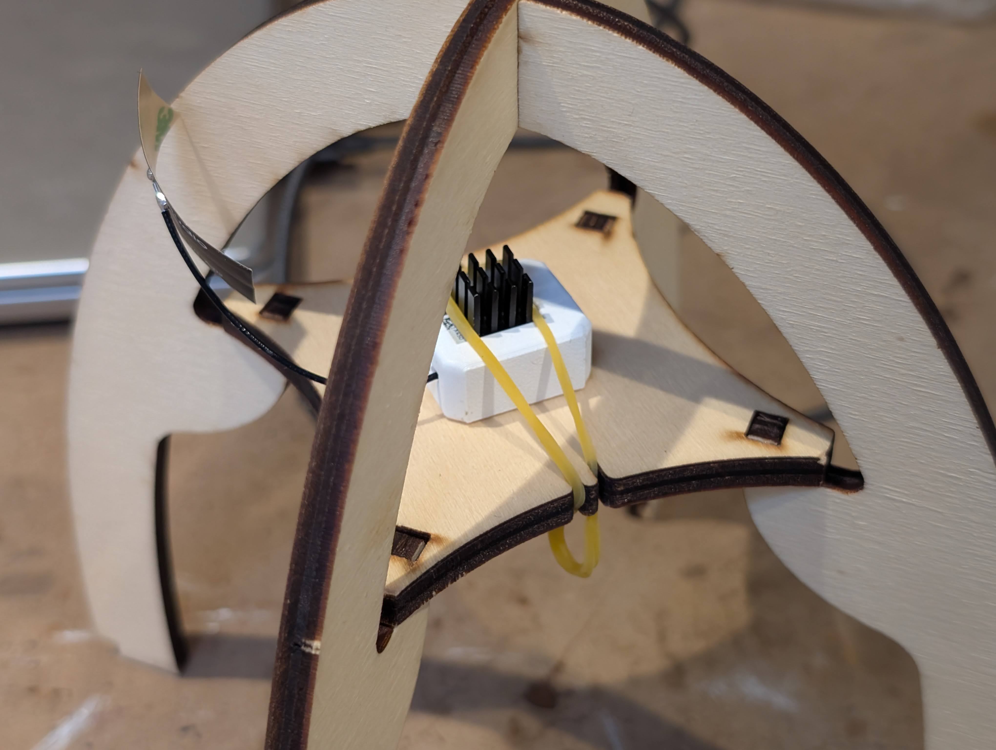
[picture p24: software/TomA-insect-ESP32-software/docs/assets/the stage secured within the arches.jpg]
The platform secured in place inside the arch — your camera, fully built


Great job — your camera is built! Now let's run it. 🎉

## Let's go!

1

### Put the picture of ants under the camera

This is what the camera will practice looking at. Line it up so it's nice and flat underneath the lens.

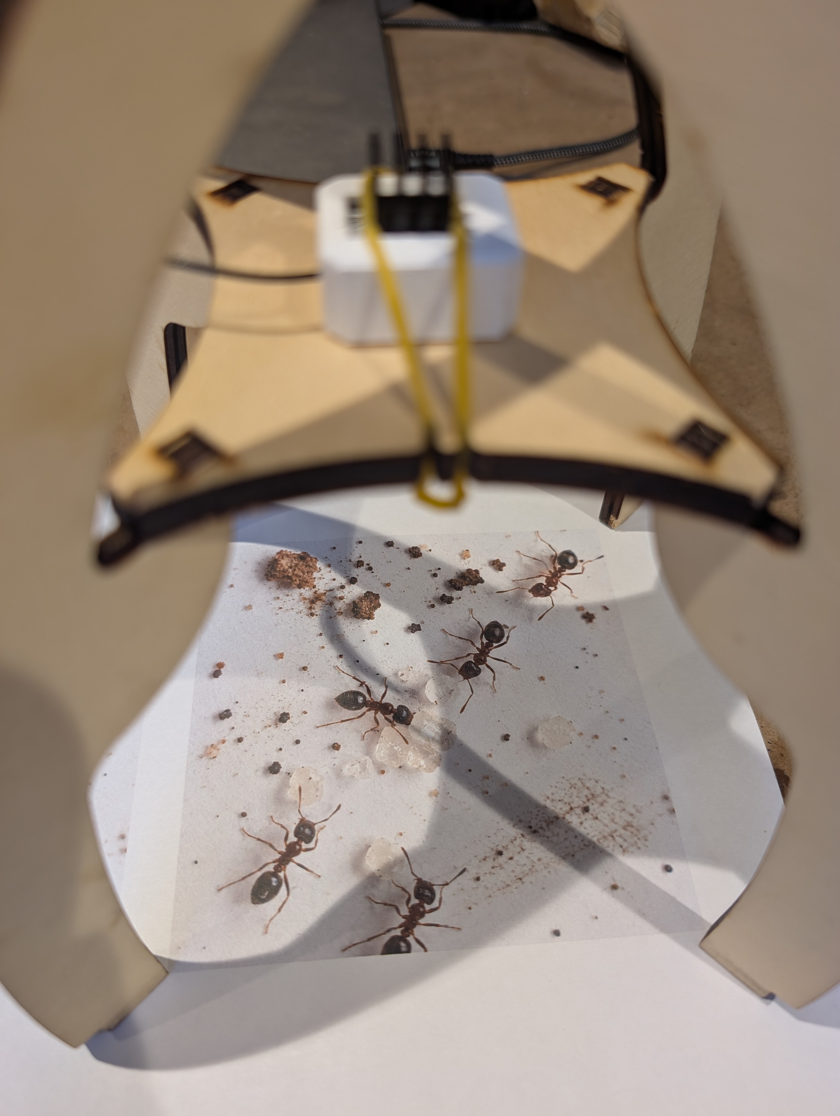
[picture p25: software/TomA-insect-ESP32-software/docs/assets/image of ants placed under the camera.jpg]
The ant picture placed under the camera


2

### Plug in the battery

As soon as you connect the battery cable, the camera wakes up and starts taking a photo every second — all on its own!

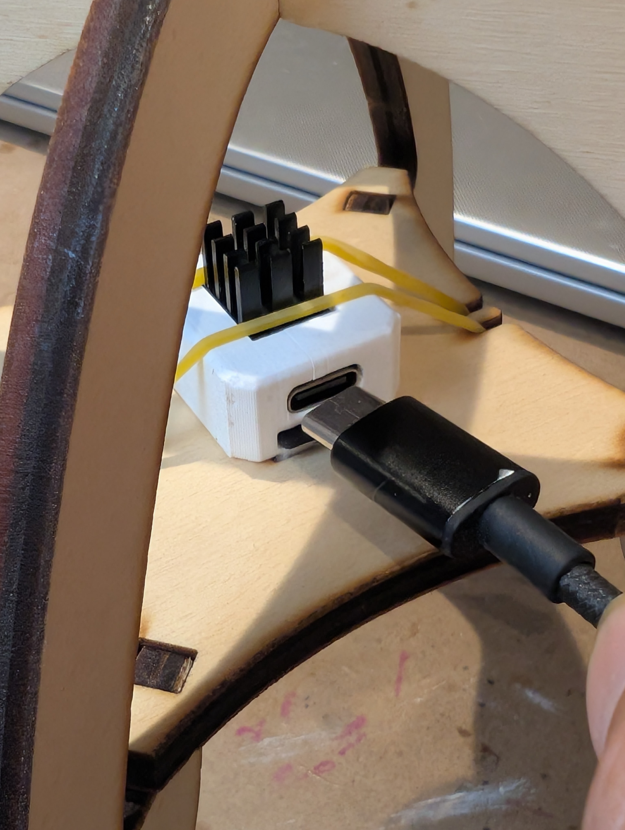
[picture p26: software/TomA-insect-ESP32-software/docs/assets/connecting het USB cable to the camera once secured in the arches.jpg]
Connecting the USB cable to power up the camera


3

### Join the camera's Wi-Fi with your phone

Open your phone's Wi-Fi settings and look for a network starting with InsectCam- — every camera has its own name, so check the label on your camera to find yours. Tap it, then type the password. A welcome page should open by itself. (If it doesn't, ask your teacher.)

Network: InsectCam-… (see your camera's label) Password: antcamera

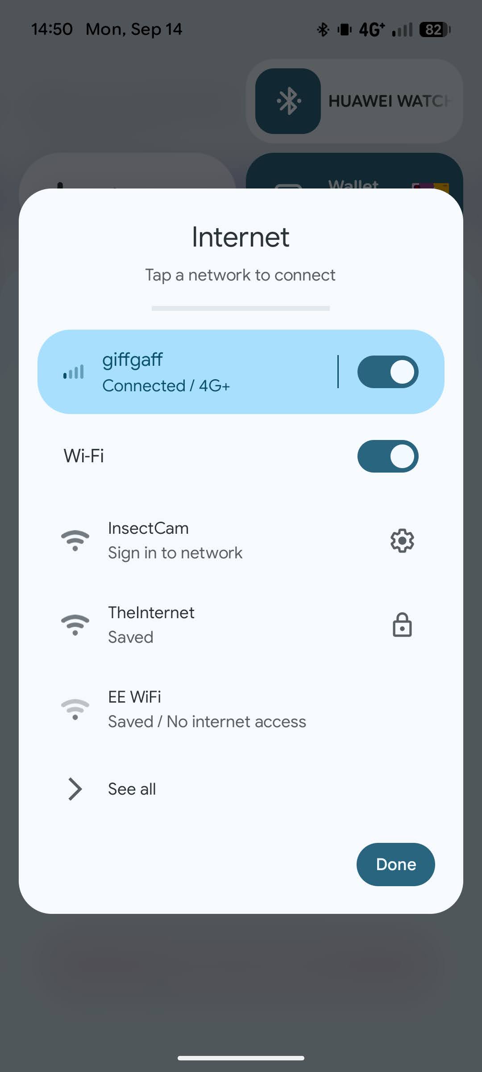
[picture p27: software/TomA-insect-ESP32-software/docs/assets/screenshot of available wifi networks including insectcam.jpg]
An InsectCam network in the phone's list of Wi-Fi networks


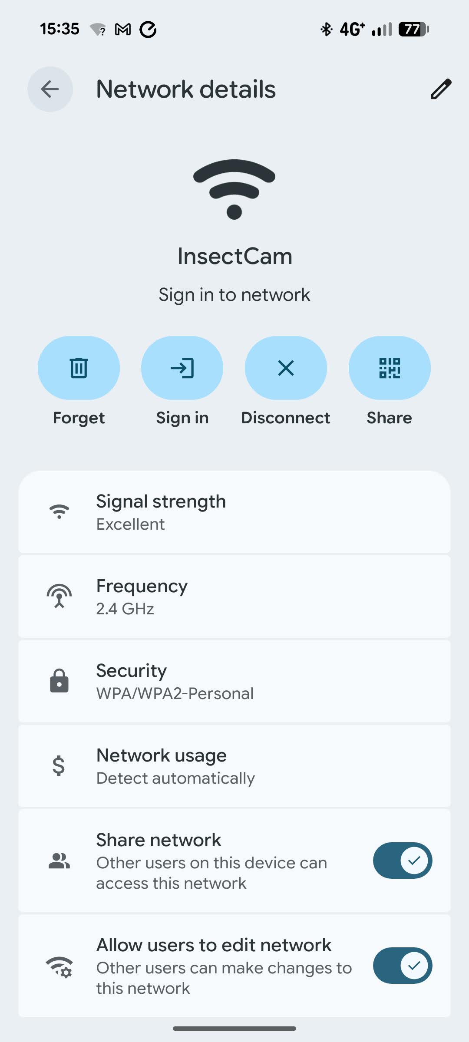
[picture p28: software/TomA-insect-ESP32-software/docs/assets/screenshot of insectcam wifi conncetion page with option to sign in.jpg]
The sign-in prompt after joining an InsectCam network


4

### Take a peek

On the welcome page, tap 👁️ Take a peek to see the most recent photo the camera has just taken — live! Watch the pictures for about a minute while the camera keeps working.

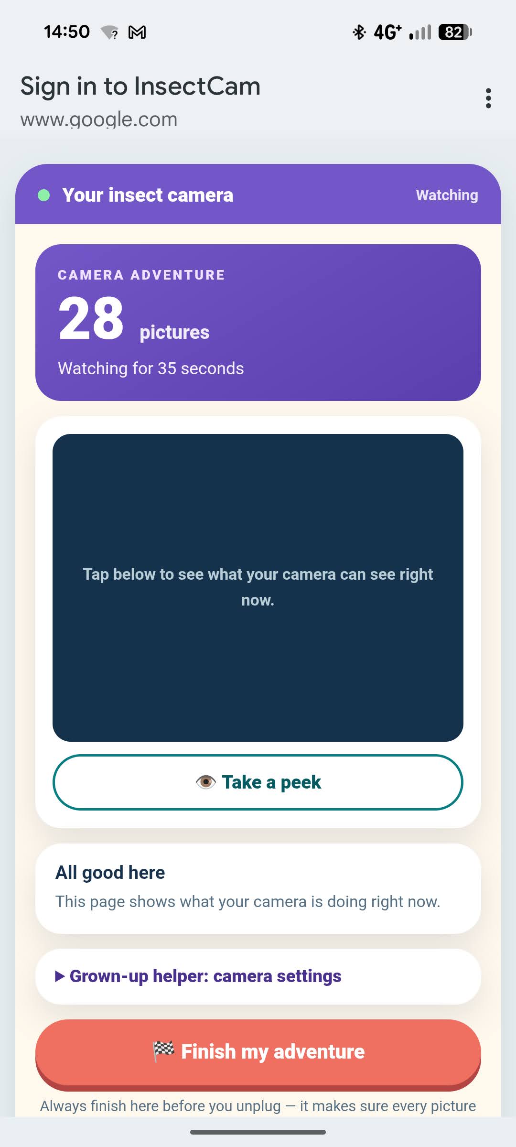
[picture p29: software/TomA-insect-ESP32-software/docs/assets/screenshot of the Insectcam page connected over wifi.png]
The InsectCam page once connected, with the Take a peek button


5

### Finish the adventure

When you're ready to stop, tap 🏁 Finish my adventure. Wait for it to say it's done — this makes sure all your photos are saved safely before you touch anything.

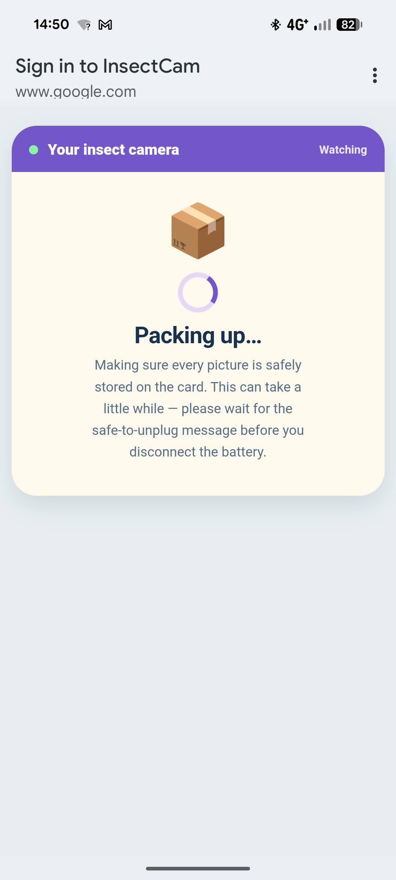
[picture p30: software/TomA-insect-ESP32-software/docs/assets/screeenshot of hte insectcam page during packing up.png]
The InsectCam page while it is packing up


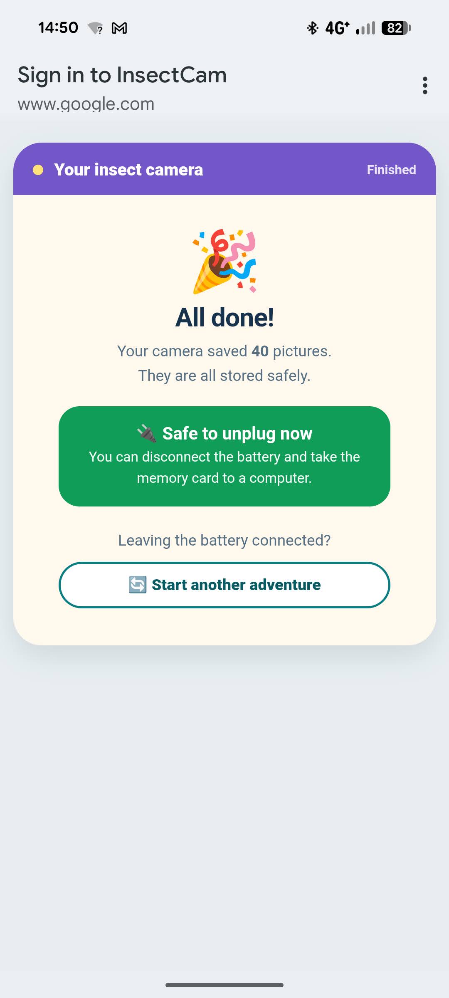
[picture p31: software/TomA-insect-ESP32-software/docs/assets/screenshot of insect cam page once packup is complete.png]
The InsectCam page confirming pack-up is complete


## Now let's find the bugs!

6

### Unplug and open up the card

Disconnect the battery cable, carefully take out the memory card, and put it into a computer.

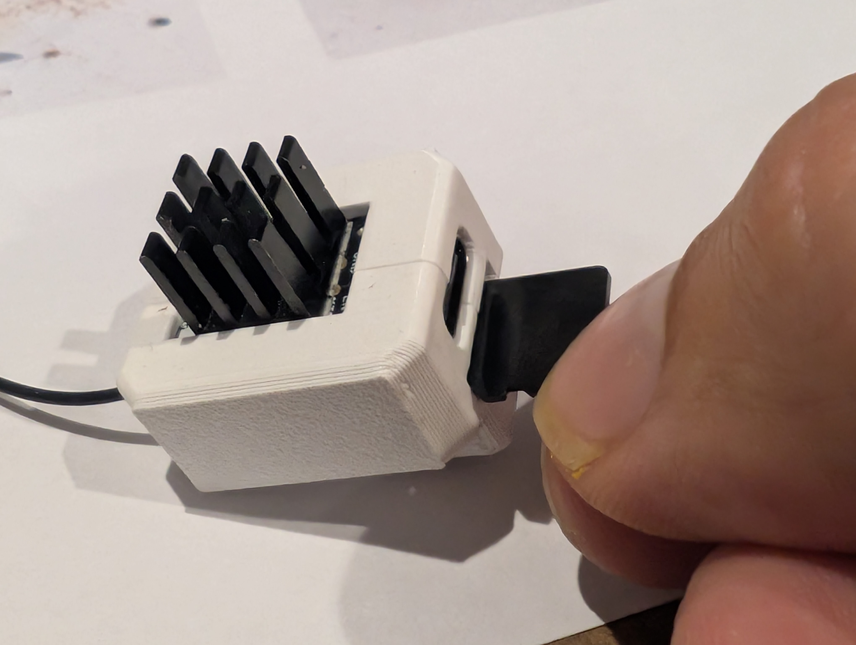
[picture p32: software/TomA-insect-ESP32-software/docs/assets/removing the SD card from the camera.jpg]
Removing the SD card from the camera


7

### Open the picture gallery

On the computer, open the file called dashboard.html that's on the card — you don't need to install anything, just open it like any other file and it opens in your web browser. It shows every photo the camera just took — no internet needed, it all works right there on the card!

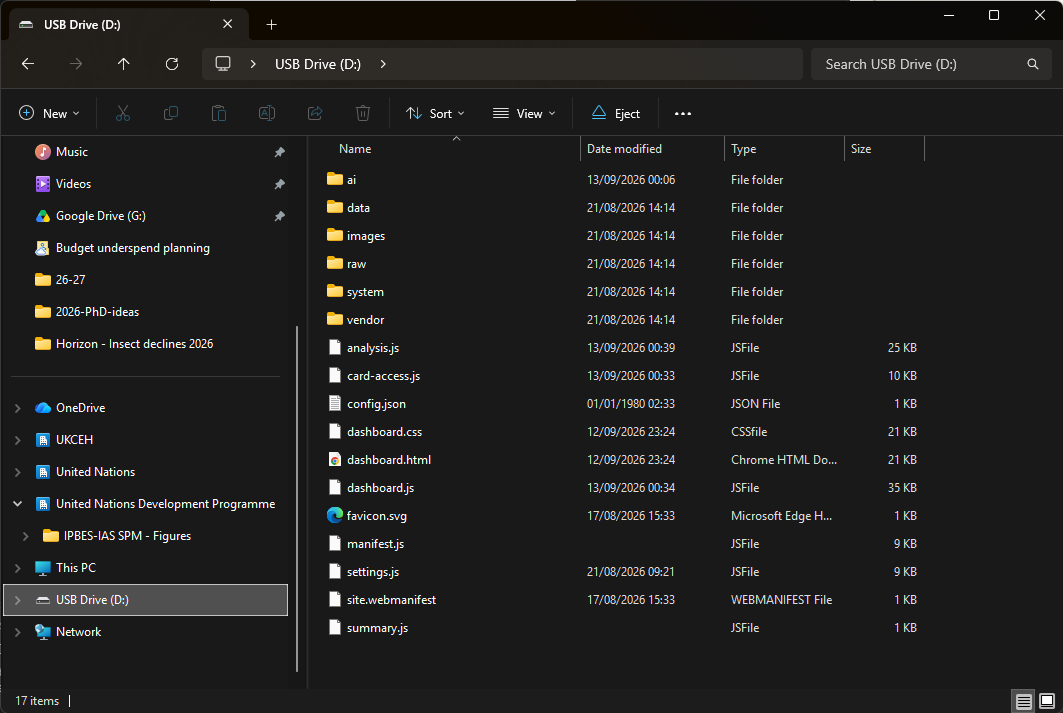
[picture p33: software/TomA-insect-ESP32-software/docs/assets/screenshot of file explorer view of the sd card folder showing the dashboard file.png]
The SD card's folder, with dashboard.html visible


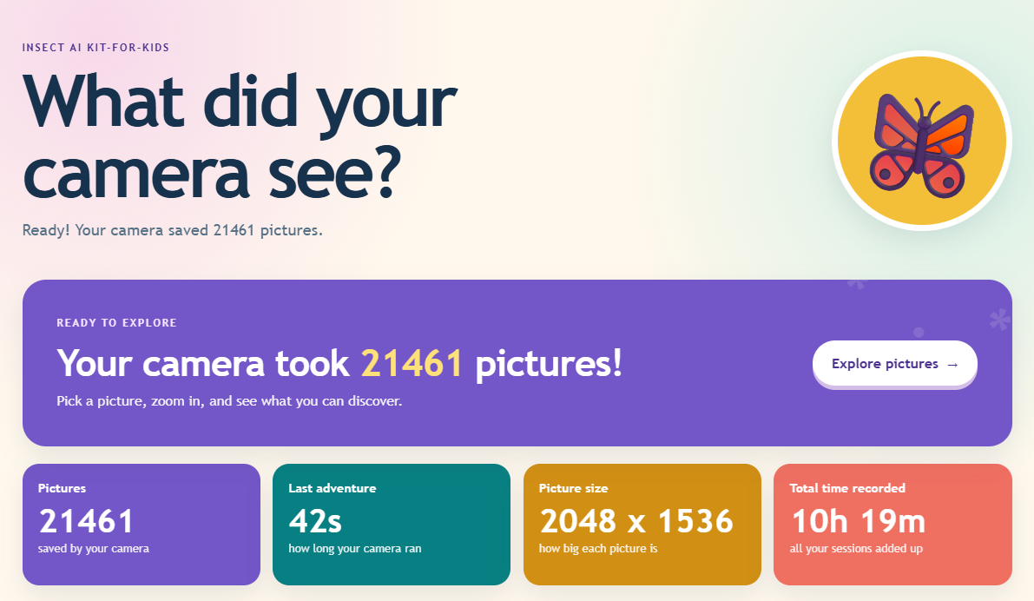
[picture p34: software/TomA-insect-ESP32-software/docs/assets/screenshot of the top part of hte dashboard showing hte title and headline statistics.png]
The dashboard, open and showing today's picture count


8

### Load your pictures for the AI

Click Find insects with AI, then click Load camera card →. In the window that opens, choose your USB drive or SD card (look for INSECT-AI) and click OK. The browser will then ask if it's okay to look at all the files — click OK (or Upload) to allow it. Nothing is actually uploaded anywhere; this just lets the page on your computer read the pictures.

9

### Let the AI look for insects

Pick FlatBug — Quick look, an AI model that has been trained to spot insects in photos. Watch as the computer looks at each photo, one at a time, and guesses where it thinks it can see an insect.

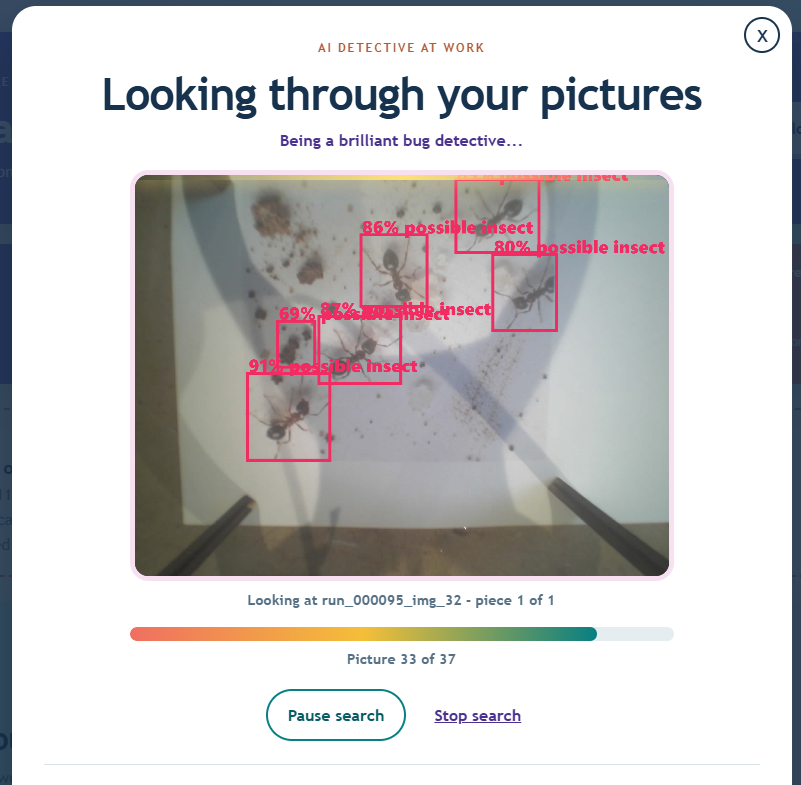
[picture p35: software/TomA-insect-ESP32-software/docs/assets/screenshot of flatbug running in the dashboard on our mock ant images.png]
FlatBug finding insects in the dashboard


That's it — you've run a real insect-monitoring camera and used AI to look for bugs, start to finish! 🎉

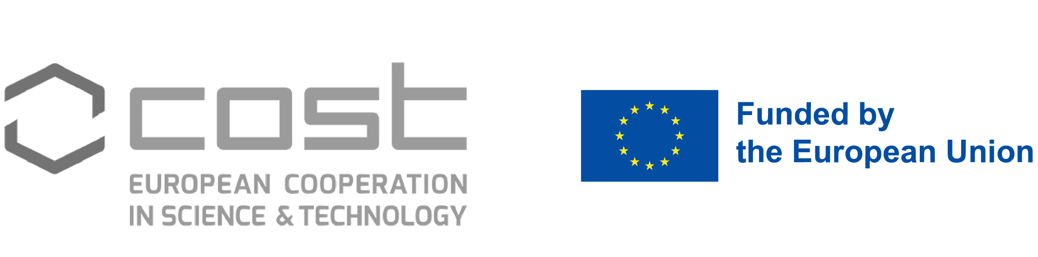
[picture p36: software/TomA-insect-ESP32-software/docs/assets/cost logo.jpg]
COST Action logo
InsectAI logo 

InsectAI COST Action · Kit-for-Kids · Bug Camera Day guide

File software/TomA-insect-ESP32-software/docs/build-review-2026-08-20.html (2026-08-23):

Kit4Kids · WG2 · Enclosure subgroup

# An insect camera a child can actually use

A battery-powered camera that watches an insect enclosure for an hour, then tells its story on any computer — no app, no server, no internet.

Pilot camera software system — objectives, functionality and method Tom August · 21 August 2026

Photo 1
night field deployment

Field test: enclosure, camera board and USB battery pack.

01 · Objectives

## What I set out to build

Six commitments, written down before any code. Each one rules something out — which is what makes them useful.

- 01Runs itselfPower on, walk away, collect unattended for up to an hour.
- 02Never loses dataPulling the battery mid-session must not corrupt what came before.
- 03No software to installCard into a laptop, double-click one file. Fully offline.
- 04Made for childrenThe first screen is a welcome, not a configuration panel.
- 05AI that stays honestAlways labelled a guess — never presented as a species identification.
- 06Open and reproduciblePinned toolchain, documented schemas, an auditable card.

The hardest constraint is #3. It has to work on a locked-down school laptop with no internet and no admin rights — which rules out every conventional web approach and shapes the whole architecture.

02 · Functionality

## Autonomous capture

The board is given no instructions in the field. Everything it needs is on the card, and the sequence is the same every time.

1. Boot and self-checkConfirm the sensor and PSRAM are present; fail visibly rather than loop.
2. Read config.jsonInterval, quality, duration, motion mode. Missing or invalid falls back to documented defaults.
3. Open the sessionNew run ID, a manifest recording the settings actually in force.
4. Warm up for five secondsLets sensor exposure settle before the first real frame.
5. Capture on a fixed clockOne frame per second, rebased if a frame runs long — never a growing backlog.

Settings are a short list, not a free-for-all. The dashboard can only offer combinations the firmware knows it can honour, and the firmware re-validates on boot.

Photo 2
enclosure in use

Laser-cut enclosure with the camera board mounted above the observation floor.

03 · Method

## Writing data that survives being unplugged

Children stop the camera by pulling the battery cable. That is the intended design — so every write assumes power can vanish mid-operation.

Per frame

One row written and flushed to captures.csv immediately — nothing is held in memory waiting for a clean shutdown

Per image

Written to a temporary name, then atomically renamed. A half-written JPEG never acquires a real filename

Directory load

Images sharded 100 to a folder, so write time stays flat deep into a long session

On next boot

An unfinished run is detected and marked interrupted, never silently resumed

The rename is the commit point. Anything interrupted before it is invisible to every reader.

04 · Method

## Keeping only what moves

An hour at one frame per second is 3,600 images, most of them identical. Optional motion triggering keeps the interesting ones — without ever hiding that a check happened.

1. Grab a tiny preview160×120 greyscale — cheap enough to take every scheduled check.
2. Score against the previous previewSplit into an 8×6 tile grid and compare tile by tile, so a small local movement is not diluted by the whole frame.
3. Correct for overall brightnessA cloud passing shifts every tile equally; that shift is subtracted so lighting changes do not read as motion.
4. Compare to a fixed thresholdAbove it, switch the sensor to full quality and save. Below it, log the check and save nothing.
5. Settle, then re-baselineAfter a full capture the sensor re-adjusts, so two frames are discarded before the next comparison.

Every check is logged either way. A skipped frame still writes a row with its score, so the record is complete and the threshold can be reviewed after the fact — the data never quietly disappears.

Still experimental. Retaining every frame remains the default; motion mode is opt-in until it has been through physical acceptance testing.

05 · Functionality

## The dashboard travels on the card

The card carries its own viewer. Put it in any Windows or Mac laptop, double-click dashboard.html, and it opens straight from the card.

Welcome

Picture count, gallery, tap any image to enlarge

Movie maker

Encodes a 60 fps MP4 time-lapse in the browser itself

Motion watch

Plots when the camera decided something moved

Camera settings

Writes a new config.json back for the next run

Adult details

Frame search and per-capture records, deliberately tucked away

How it loads without a server

A browser opening a local file cannot fetch other files freely. So the firmware writes its data as small JavaScript chunk files that the page simply includes — 100 records each, closed and promoted atomically as they fill.

One damaged chunk cannot take the page down. Each loads independently; the rest still display. The raw CSV remains the authoritative record behind them.

Nothing is uploaded, ever. No network calls, no CDN, no telemetry — the page works with the machine offline.

06 · Functionality

## Asking the computer to look

After a session, an adult can start a local search through the pictures. It runs entirely in the browser, one image at a time, with progress and a stop control.

AntAI – Beta

A small detector trained here on our own enclosure images. One pass per picture

FlatBug — quick

Open-source general insect detector, one pass per picture

FlatBug — close

Same model over 12 overlapping tiles — slower, better on small insects

Two deliberate constraints

It runs on the laptop, not the camera. These models need far more memory than the board has. Keeping the device model-free protects capture reliability — the camera's job is to capture, nothing else.

The language is held firmly. Results are described to children as possible-insect clues. No species claims and no validated-detection language until the evidence supports it — the wording is a design decision, not a caveat.

07 · Architecture

## How the whole thing fits together

The card is the whole product. It carries the pictures, the authoritative log, and the software that reads them — so the only thing that ever moves between field and desk is the card itself.

Insect camera · build review

← 1 / 8 →

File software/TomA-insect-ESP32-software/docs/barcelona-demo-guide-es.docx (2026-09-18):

🐞 🐜 🦋 🐝 🪲

¡Hoy jugamos con una cámara que detecta bichos!

Curiosidad natural + inteligencia artificial

Vais a poner en marcha una cámara para observar insectos, vais a recoger sus fotos y a dejar que un ordenador intente encontrar los bichos en ellas — ¡todo sin ayuda de nadie!

Una guía paso a paso para alumnado y profesorado · InsectAI Kit-for-Kids

🇬🇧 English · 🇪🇸 Español


Lo que necesitaréis

- Una cámara, una tarjeta SD y una antena Wi-Fi
- La carcasa de la cámara (blanca)
- La plataforma de la cámara — hecha de tres piezas de madera: dos arcos y una pieza en forma de estrella de 4 puntas
- Una goma elástica
- La foto pequeña de hormigas que se coloca debajo de la cámara
- La batería externa
- Un cable USB-C, para conectar la batería a la cámara
- Un teléfono — hoy es mejor usar uno Android
- Un portátil u ordenador para ver las fotos después

Palabras que hay que saber

IA (Inteligencia Artificial)

Un programa de ordenador que ha aprendido cómo suelen ser los insectos, y que hace una estimación de dónde podría haber uno en una foto. ¡Puede equivocarse — está adivinando, no siempre tiene razón!

Tarjeta SD

La pequeña tarjeta de memoria dentro de la cámara que guarda cada foto que hace.

Código QR

Un dibujo cuadrado especial que la cámara de tu teléfono puede leer, para que no tengas que escribir nada.

Wi-Fi

Así es como tu teléfono habla con la cámara sin cables, para que puedas ver sus fotos mientras está trabajando.

Notas para el profesorado / persona facilitadora

- Espera siempre a que 🏁 Termina tu aventura lo confirme antes de sacar la tarjeta — así es como se guardan las fotos de forma segura.
- Nunca saques la tarjeta SD mientras la cámara sigue encendida.
- Cada cámara tiene su propio nombre de Wi-Fi (InsectCam- más una etiqueta corta), así que varias cámaras pueden funcionar en la misma sala sin confundirse — comprueba que cada cámara tiene su nombre bien visible antes de empezar.

# ¡Monta tu cámara!

1 | Conecta la antena y coloca la tarjeta de memoria

Si la antena y la tarjeta SD todavía no están conectadas, enchufa la pequeña antena Wi-Fi a la placa de la cámara y desliza la tarjeta de memoria en su ranura. Esto es lo que la cámara usará para hablar con tu teléfono y para guardar cada foto que haga.

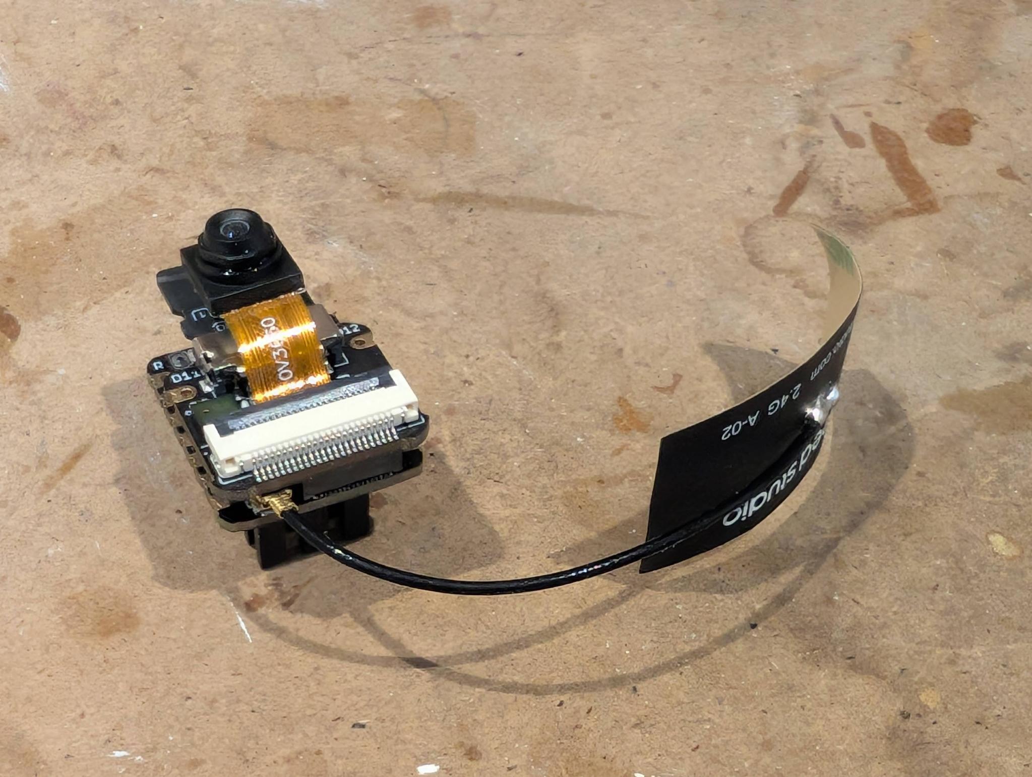
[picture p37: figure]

2 | Ciérrala dentro de su carcasa

Si la placa de la cámara todavía no está en la carcasa, colócala con cuidado dentro de la carcasa blanca para que el objetivo asome por el agujero, y después cierra la carcasa.

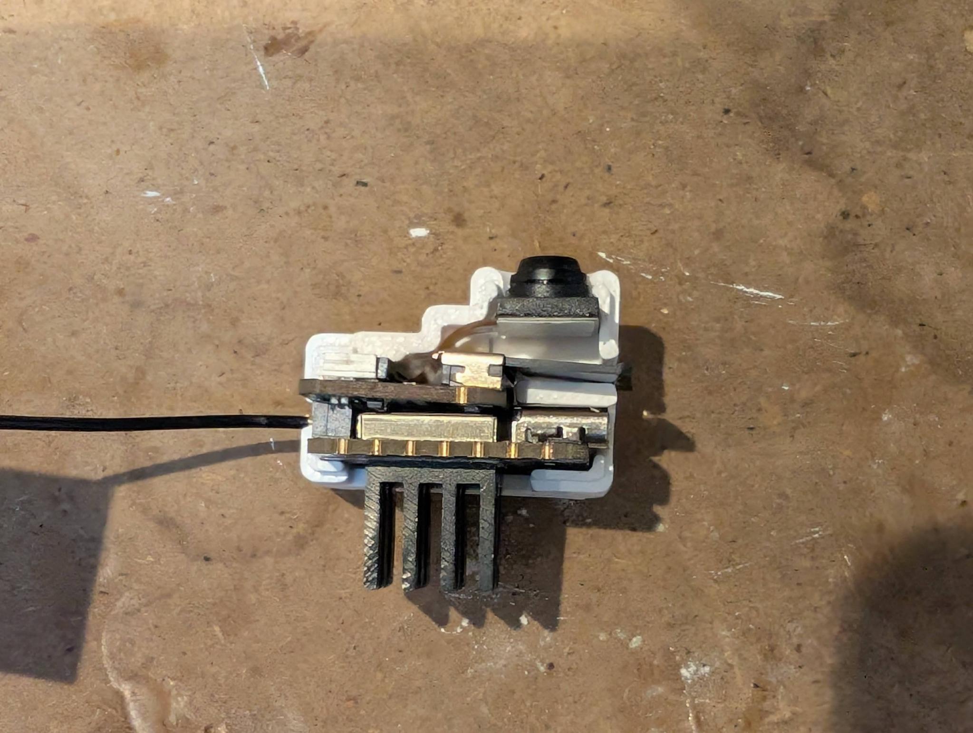
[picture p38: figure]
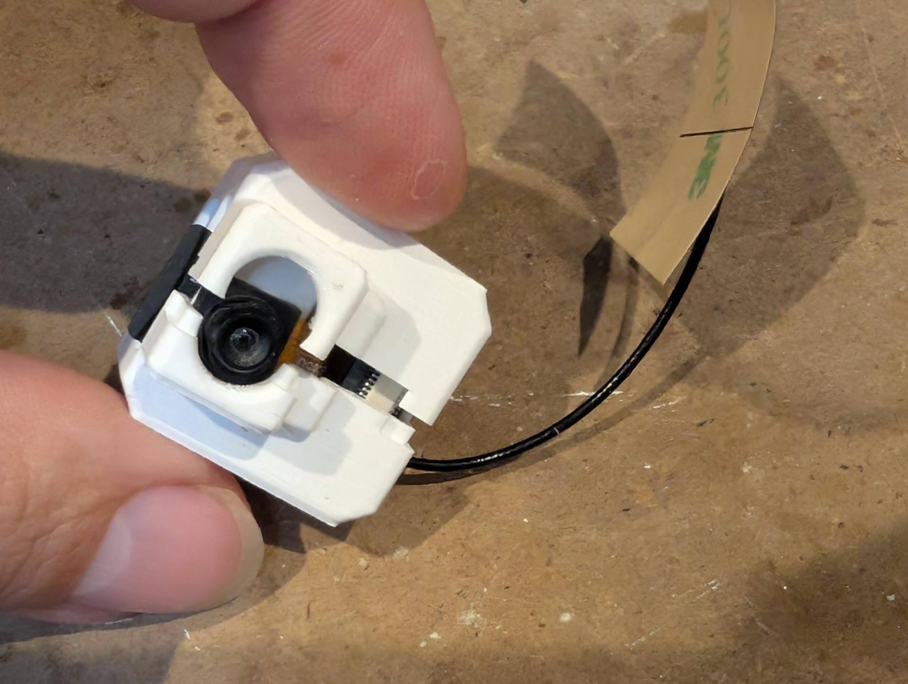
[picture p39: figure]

3 | Sujétala a la plataforma en forma de estrella

Coloca la cámara en la plataforma de madera en forma de estrella, de modo que la cámara encaje en el agujero del centro. Estira la goma elástica por encima, usando los ganchos de cada lado para que la goma rodee el disipador de calor, presionando la cámara dentro del agujero del centro.

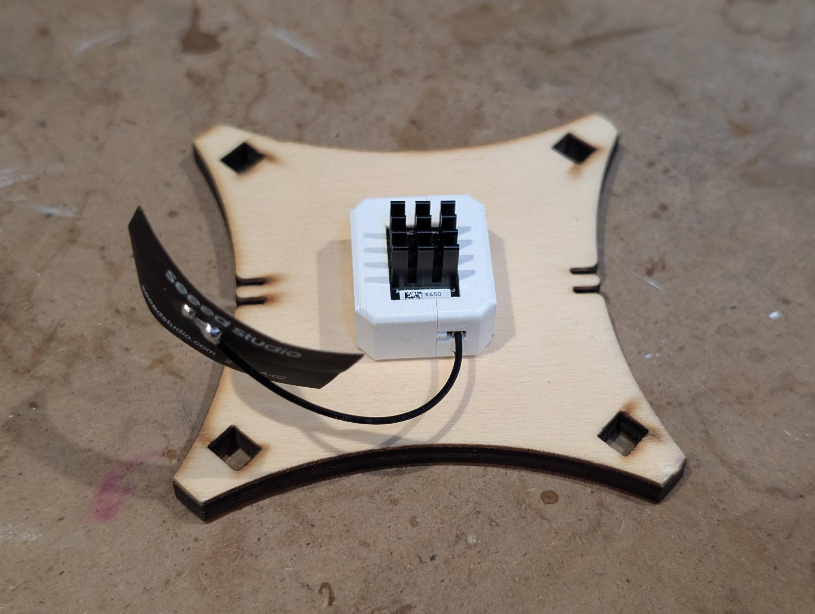
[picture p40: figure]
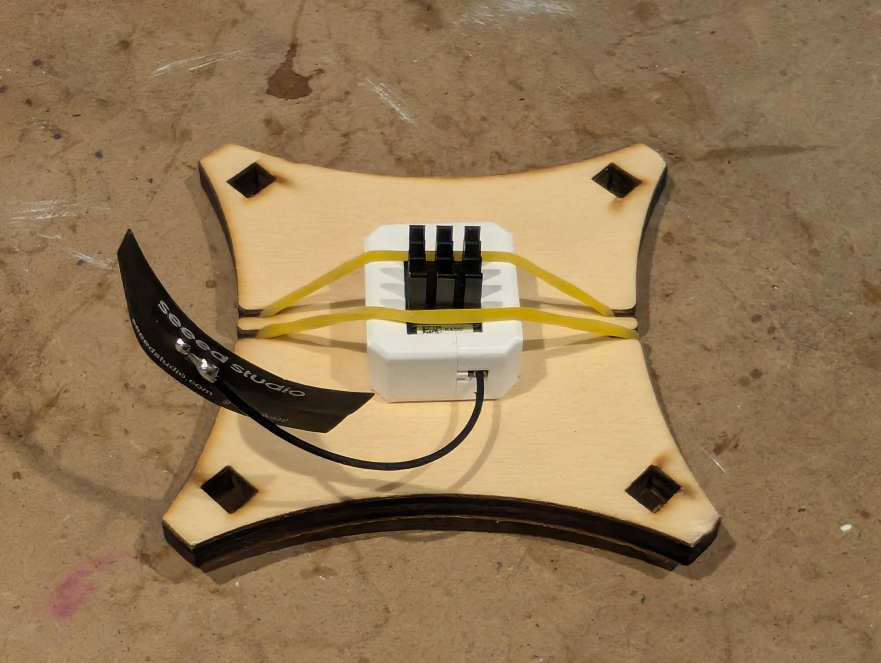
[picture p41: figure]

4 | Monta el arco

Encaja las dos piezas curvas de madera del arco por arriba, para que se sostengan juntas sobre sus cuatro patas.

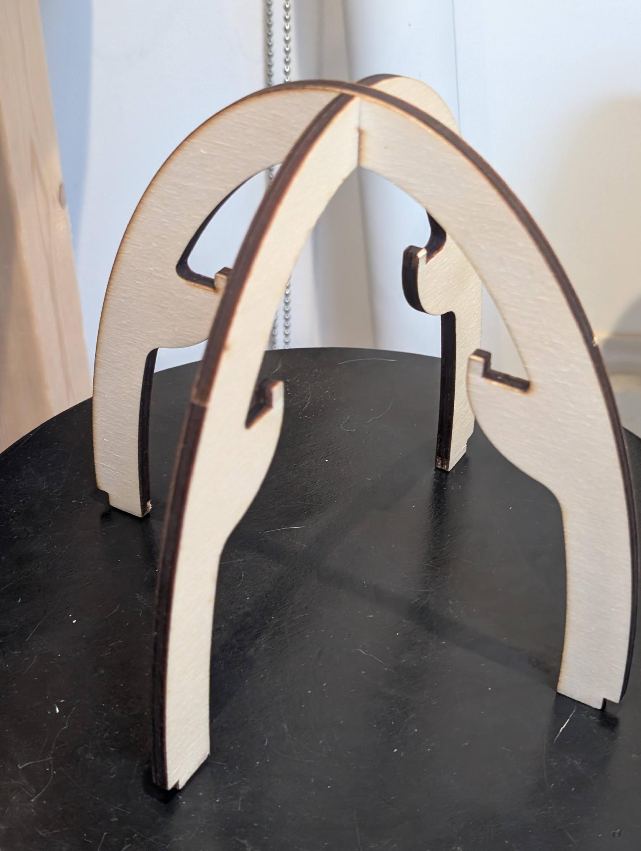
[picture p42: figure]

5 | Desliza la plataforma dentro del arco

Levanta la plataforma en forma de estrella —con la cámara sujeta a ella— hacia dentro del arco. Cuando llegue arriba del todo, gírala y bájala hasta las muescas, encajándola con cuidado.

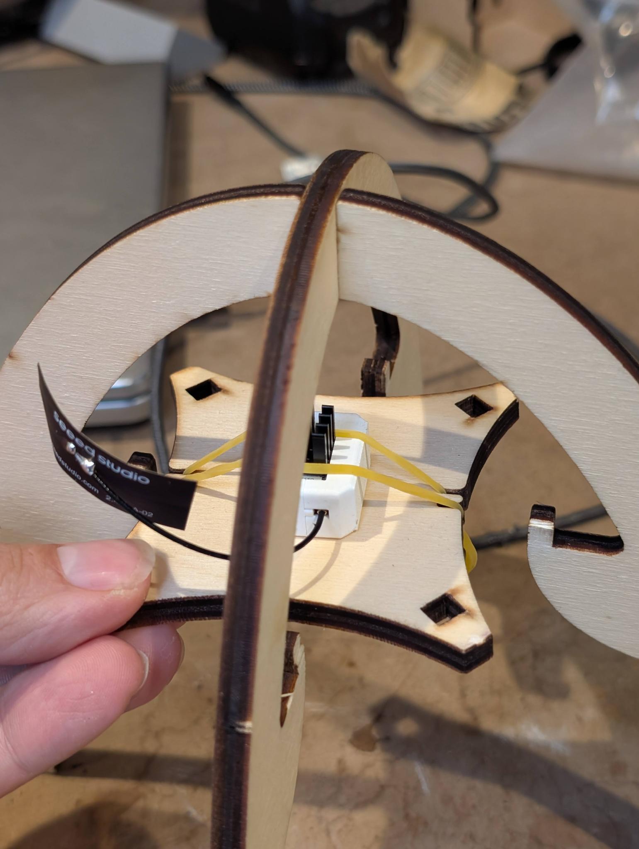
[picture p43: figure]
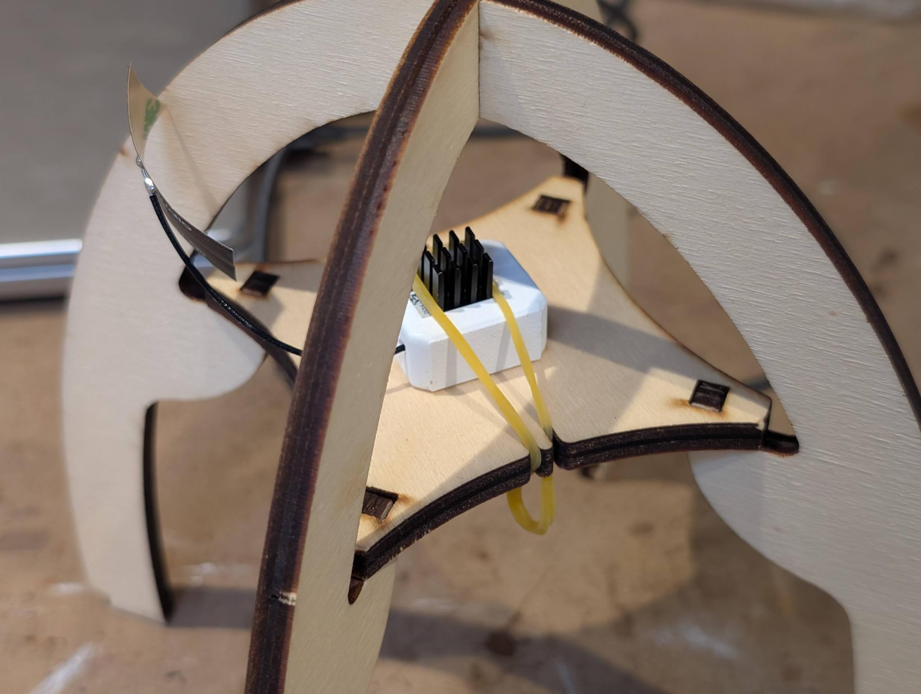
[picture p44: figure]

¡Muy bien hecho — tu cámara ya está montada! Ahora vamos a ponerla en marcha. 🎉

# ¡Vamos allá!

1 | Pon la foto de hormigas debajo de la cámara

Esto es lo que la cámara va a usar para practicar. Colócala bien recta y plana justo debajo del objetivo.

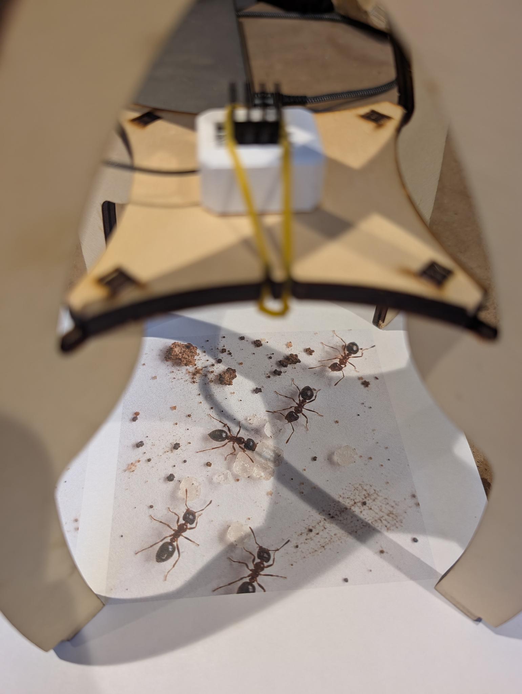
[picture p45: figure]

2 | Enchufa la batería

En cuanto conectes el cable de la batería, la cámara se despierta y empieza a hacer una foto cada segundo — ¡ella solita!

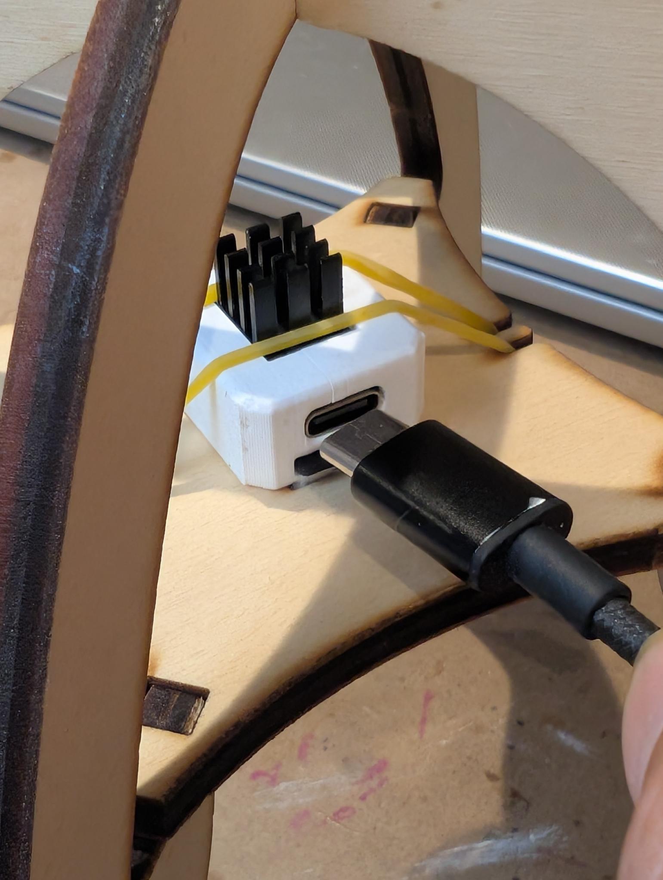
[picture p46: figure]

3 | Conecta tu teléfono al Wi-Fi de la cámara

Abre los ajustes de Wi-Fi de tu teléfono y busca una red que empiece por InsectCam- — cada cámara tiene su propio nombre, así que mira la etiqueta de tu cámara para encontrar el tuyo. Tócala y escribe la contraseña. Debería abrirse sola una página de bienvenida. (Si no se abre, pregunta a tu profe.)

Red: InsectCam-… (mira la etiqueta de tu cámara) Contraseña: antcamera

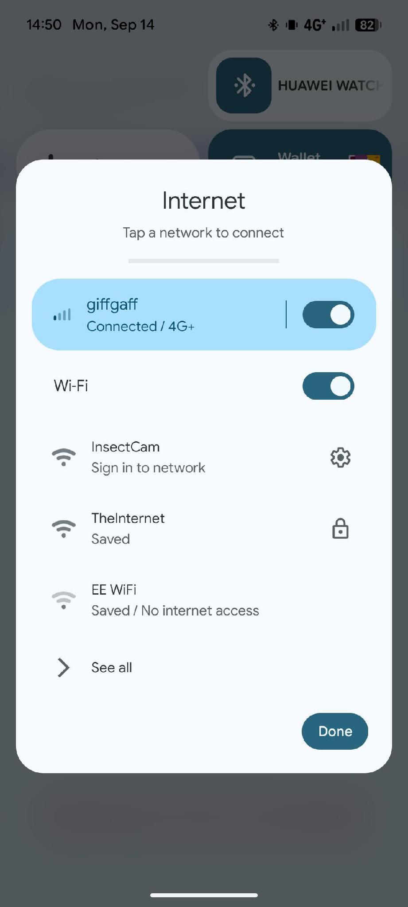
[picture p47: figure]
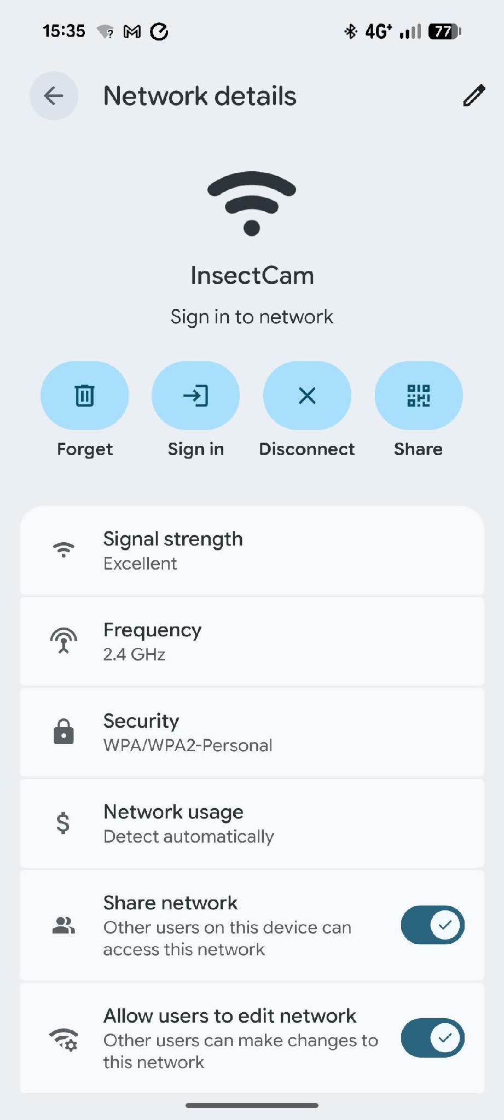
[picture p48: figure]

4 | Echa un vistazo

En la página de bienvenida, toca 👁️ Echa un vistazo para ver la foto más reciente que acaba de hacer la cámara — ¡en directo! Mira las fotos durante un minuto más o menos mientras la cámara sigue trabajando.

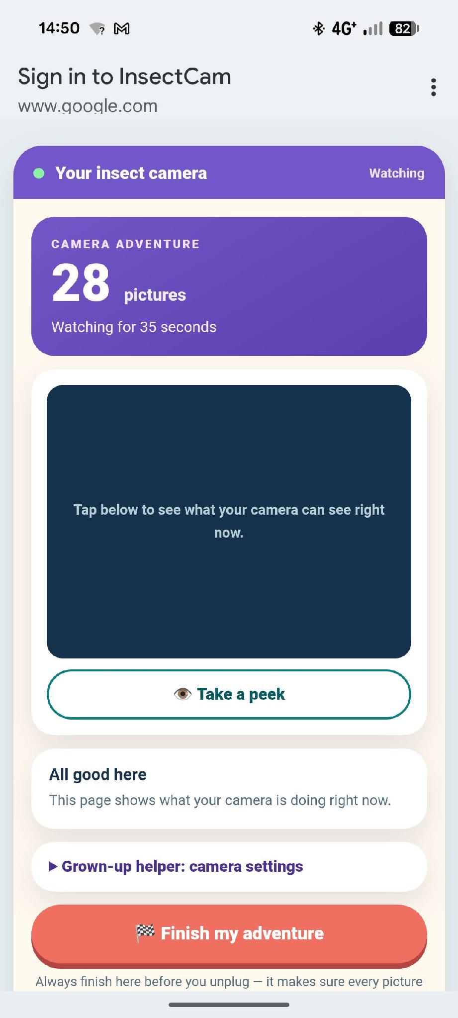
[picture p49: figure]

5 | Termina la aventura

Cuando quieras parar, toca 🏁 Termina tu aventura. Espera a que diga que ha terminado — así te aseguras de que todas tus fotos se han guardado bien antes de tocar nada.

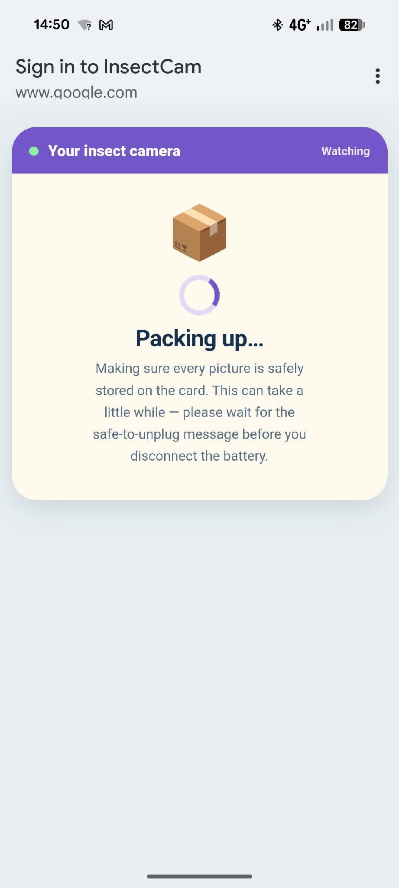
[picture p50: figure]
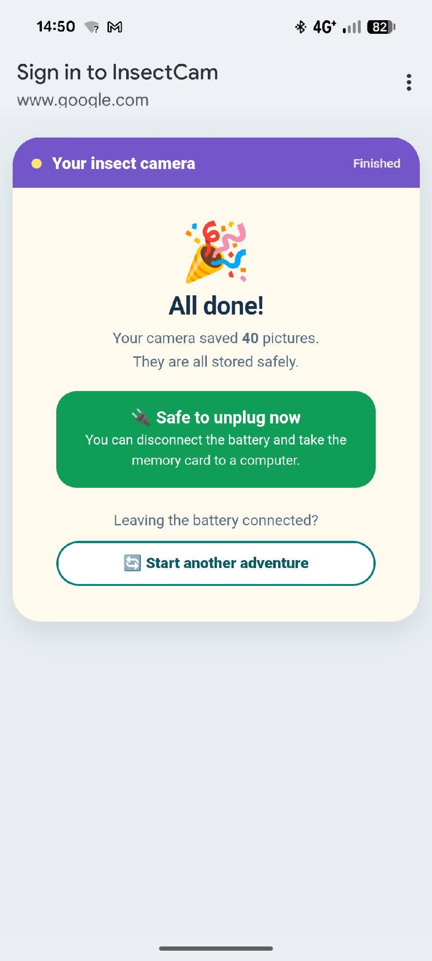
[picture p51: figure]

# ¡Ahora vamos a buscar los bichos!

6 | Desconecta y saca la tarjeta

Desconecta el cable de la batería, saca con cuidado la tarjeta de memoria, e introdúcela en un ordenador.

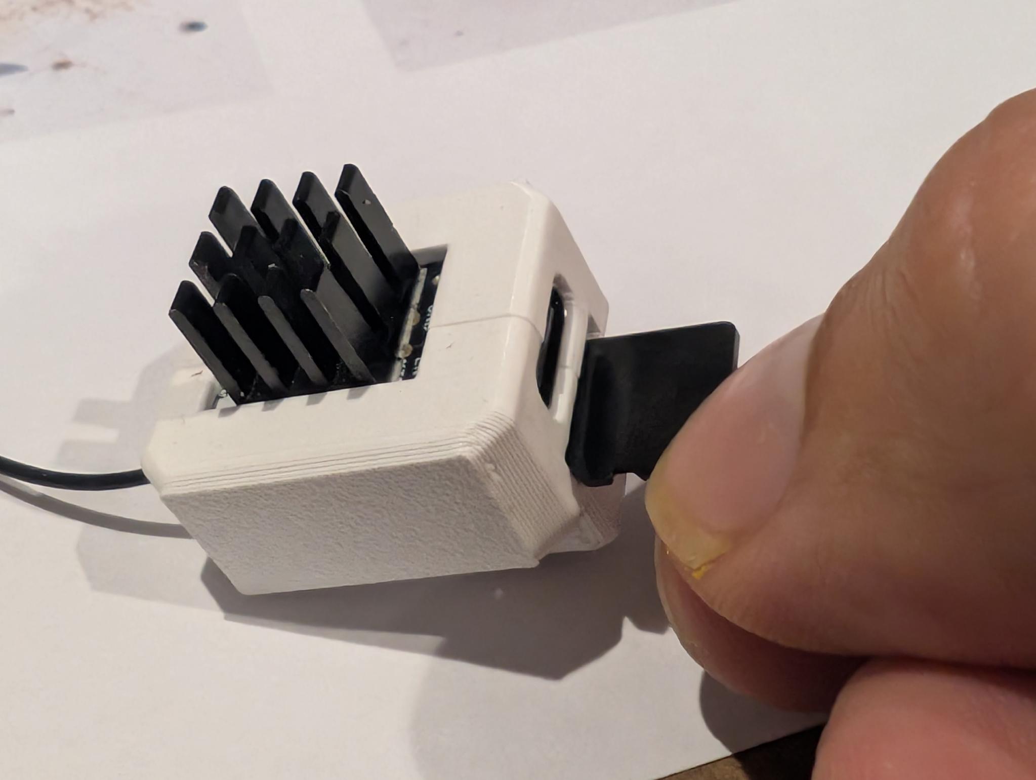
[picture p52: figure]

7 | Abre la galería de fotos

En el ordenador, abre el archivo llamado dashboard.html que hay en la tarjeta — no necesitas instalar nada, ábrelo como cualquier otro archivo y se abrirá en tu navegador. Muestra todas las fotos que acaba de hacer la cámara — no hace falta internet, ¡todo funciona ahí mismo, en la tarjeta!


8 | Carga tus fotos para la IA

Haz clic en Buscar insectos con IA, y después en Cargar tarjeta de la cámara →. En la ventana que se abre, elige tu unidad USB o tarjeta SD (busca INSECT-AI) y haz clic en Aceptar. El navegador preguntará entonces si puede mirar todos los archivos — haz clic en Aceptar (o Subir) para permitirlo. En realidad no se sube nada a ningún sitio: esto solo deja que la página de tu ordenador lea las fotos.

9 | Deja que la IA busque insectos

Elige FlatBug — Vistazo rápido, un modelo de IA entrenado para encontrar insectos en fotos. Observa cómo el ordenador mira cada foto, una por una, y adivina dónde cree que puede ver un insecto.


¡Y ya está — has puesto en marcha una cámara de verdad para vigilar insectos y has usado la IA para buscar bichos, de principio a fin! 🎉

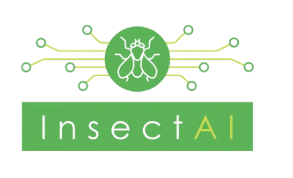
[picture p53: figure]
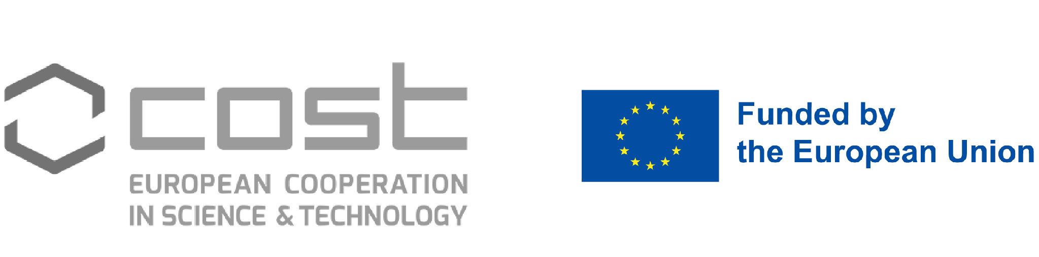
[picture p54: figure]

InsectAI COST Action · Kit-for-Kids · Guía del día de la cámara de bichos

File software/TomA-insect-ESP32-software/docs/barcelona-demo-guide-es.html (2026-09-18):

🐞 🐜 🦋 🐝 🪲

# ¡Día de la cámara de bichos!

Hoy vais a poner en marcha una cámara de insectos de verdad, vais a recoger sus fotos y vais a dejar que un ordenador intente encontrar los bichos en ellas — ¡todo vosotros solos!

Una guía paso a paso para alumnado y profesorado · InsectAI Kit-for-Kids

🇬🇧 English · 🇪🇸 Español

La cámara de insectos terminada, totalmente montada

## Lo que necesitaréis

- Una cámara, una tarjeta SD y una antena Wi-Fi
- La carcasa de la cámara (blanca)
- La plataforma de la cámara — hecha de tres piezas de madera: dos arcos y una pieza en forma de estrella de 4 puntas
- Una goma elástica
- La foto pequeña de hormigas que se coloca debajo de la cámara
- La batería externa
- Un cable USB-C, para conectar la batería a la cámara
- Un teléfono — hoy es mejor usar uno Android
- Un portátil u ordenador para ver las fotos después

## Palabras que hay que saber

IA (Inteligencia Artificial)

Un programa de ordenador que ha aprendido cómo suelen ser los insectos, y que hace una estimación de dónde podría haber uno en una foto. ¡Puede equivocarse — está adivinando, no está seguro!

Tarjeta SD

La pequeña tarjeta de memoria dentro de la cámara que guarda cada foto que hace.

Código QR

Un dibujo cuadrado especial que la cámara de tu teléfono puede leer, para que no tengas que escribir nada.

Wi-Fi

Así es como tu teléfono habla con la cámara sin cables, para que puedas ver sus fotos mientras está trabajando.

Notas para el profesorado / persona facilitadora

- Espera siempre a que 🏁 Termina tu aventura lo confirme antes de sacar la tarjeta — así es como se guardan las fotos de forma segura.
- Nunca saques la tarjeta SD mientras la cámara sigue encendida.
- Cada cámara tiene su propio nombre de Wi-Fi (InsectCam- más una etiqueta corta), así que varias cámaras pueden funcionar en la misma sala sin confundirse — comprueba que cada cámara tiene su nombre bien visible antes de empezar.

## ¡Monta tu cámara!

1

### Conecta la antena y coloca la tarjeta de memoria

Si la antena y la tarjeta SD todavía no están conectadas, enchufa la pequeña antena Wi-Fi a la placa de la cámara y desliza la tarjeta de memoria en su ranura. Esto es lo que la cámara usará para hablar con tu teléfono y para guardar cada foto que haga.

La placa de la cámara y la antena Wi-Fi antes de montarlas

2

### Ciérrala dentro de su carcasa

Si la placa de la cámara todavía no está en la carcasa, colócala con cuidado dentro de la carcasa blanca para que el objetivo asome por el agujero, y después cierra la carcasa.

La placa de la cámara encajada en la primera mitad de la carcasa

Colocando la segunda mitad de la carcasa encima

3

### Sujétala a la plataforma en forma de estrella

Coloca la cámara en la plataforma de madera en forma de estrella, de modo que la cámara encaje en el agujero del centro. Estira la goma elástica por encima, usando los ganchos de cada lado para que la goma rodee el disipador de calor, presionando la cámara dentro del agujero del centro.

Colocando la carcasa sobre la plataforma en forma de estrella

Sujetando la carcasa a la plataforma con la goma elástica

4

### Monta el arco

Encaja las dos piezas curvas de madera del arco por arriba, para que se sostengan juntas sobre sus cuatro patas.

Las dos piezas del arco encajadas

5

### Desliza la plataforma dentro del arco

Levanta la plataforma en forma de estrella —con la cámara sujeta a ella— hacia dentro del arco. Cuando llegue arriba del todo, gírala y bájala hasta las muescas, encajándola con cuidado.

Bajando la plataforma dentro del arco

La plataforma bien sujeta dentro del arco — tu cámara, ya montada

¡Muy bien hecho — tu cámara ya está montada! Ahora vamos a ponerla en marcha. 🎉

## ¡Vamos allá!

1

### Pon la foto de hormigas debajo de la cámara

Esto es lo que la cámara va a practicar mirando. Colócala bien recta y plana justo debajo del objetivo.

La foto de hormigas colocada debajo de la cámara

2

### Enchufa la batería

En cuanto conectes el cable de la batería, la cámara se despierta y empieza a hacer una foto cada segundo — ¡ella solita!

Conectando el cable USB para encender la cámara

3

### Conecta tu teléfono al Wi-Fi de la cámara

Abre los ajustes de Wi-Fi de tu teléfono y busca una red que empiece por InsectCam- — cada cámara tiene su propio nombre, así que mira la etiqueta de tu cámara para encontrar el tuyo. Tócala y escribe la contraseña. Debería abrirse sola una página de bienvenida. (Si no se abre, pregunta a tu profe.)

Red: InsectCam-… (mira la etiqueta de tu cámara) Contraseña: antcamera

Una red InsectCam en la lista de redes Wi-Fi del teléfono

El aviso para iniciar sesión después de unirte a una red InsectCam

4

### Echa un vistazo

En la página de bienvenida, toca 👁️ Echa un vistazo para ver la foto más reciente que acaba de hacer la cámara — ¡en directo! Mira las fotos durante un minuto más o menos mientras la cámara sigue trabajando.

La página de InsectCam ya conectada, con el botón Echa un vistazo

5

### Termina la aventura

Cuando quieras parar, toca 🏁 Termina tu aventura. Espera a que diga que ha terminado — así te aseguras de que todas tus fotos se han guardado bien antes de tocar nada.

La página de InsectCam mientras lo está guardando todo

La página de InsectCam confirmando que ya ha terminado de guardarlo todo

## ¡Ahora vamos a buscar los bichos!

6

### Desconecta y saca la tarjeta

Desconecta el cable de la batería, saca con cuidado la tarjeta de memoria, e introdúcela en un ordenador.

Sacando la tarjeta SD de la cámara

7

### Abre la galería de fotos

En el ordenador, abre el archivo llamado dashboard.html que hay en la tarjeta — no necesitas instalar nada, ábrelo como cualquier otro archivo y se abrirá en tu navegador. Muestra todas las fotos que acaba de hacer la cámara — no hace falta internet, ¡todo funciona ahí mismo, en la tarjeta!

La carpeta de la tarjeta SD, con dashboard.html a la vista

El panel abierto, mostrando el número de fotos de hoy

8

### Carga tus fotos para la IA

Haz clic en Buscar insectos con IA, y después en Cargar tarjeta de la cámara →. En la ventana que se abre, elige tu unidad USB o tarjeta SD (busca INSECT-AI) y haz clic en Aceptar. El navegador preguntará entonces si puede mirar todos los archivos — haz clic en Aceptar (o Subir) para permitirlo. En realidad no se sube nada a ningún sitio: esto solo deja que la página de tu ordenador lea las fotos.

9

### Deja que la IA busque insectos

Elige FlatBug — Vistazo rápido, un modelo de IA entrenado para encontrar insectos en fotos. Observa cómo el ordenador mira cada foto, una por una, y adivina dónde cree que puede ver un insecto.

FlatBug encontrando insectos en el panel

¡Y ya está — has puesto en marcha una cámara de verdad para vigilar insectos y has usado la IA para buscar bichos, de principio a fin! 🎉

Logo de InsectAI Logo de COST Action

InsectAI COST Action · Kit-for-Kids · Guía del día de la cámara de bichos

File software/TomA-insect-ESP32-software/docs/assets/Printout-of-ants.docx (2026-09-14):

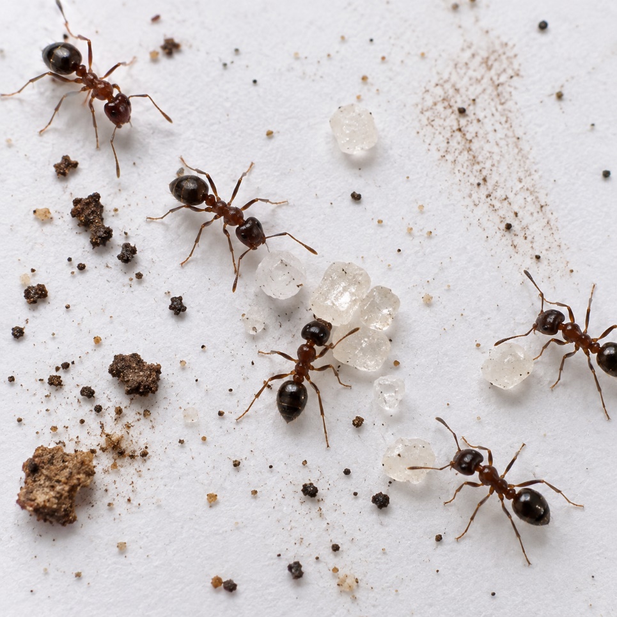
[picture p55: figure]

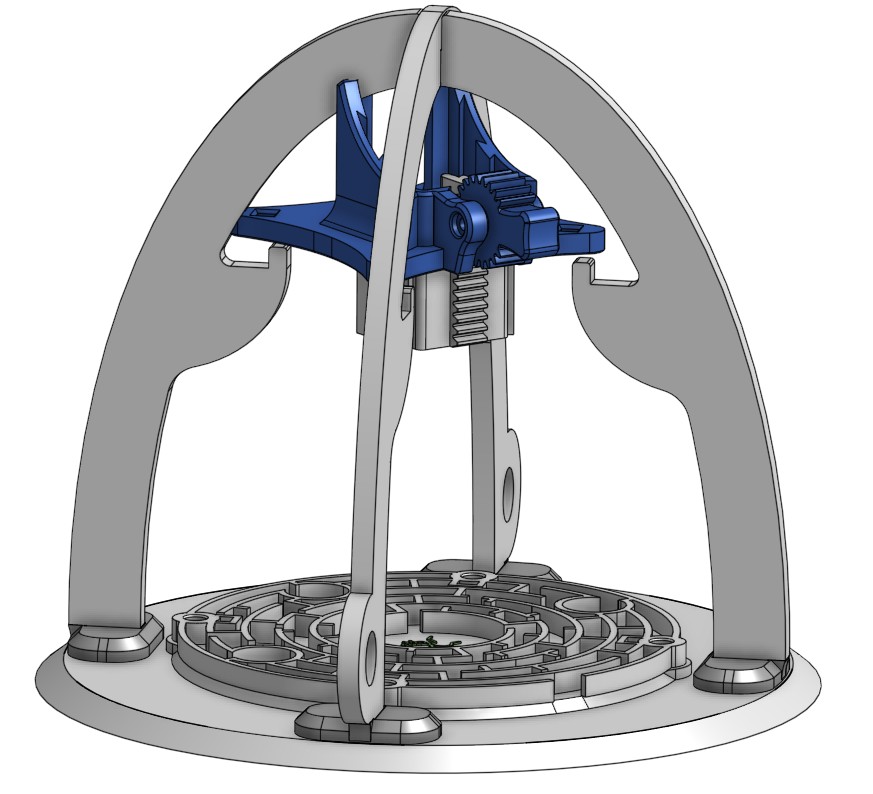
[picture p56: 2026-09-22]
3D Printed Files/Render/Image-002.jpg

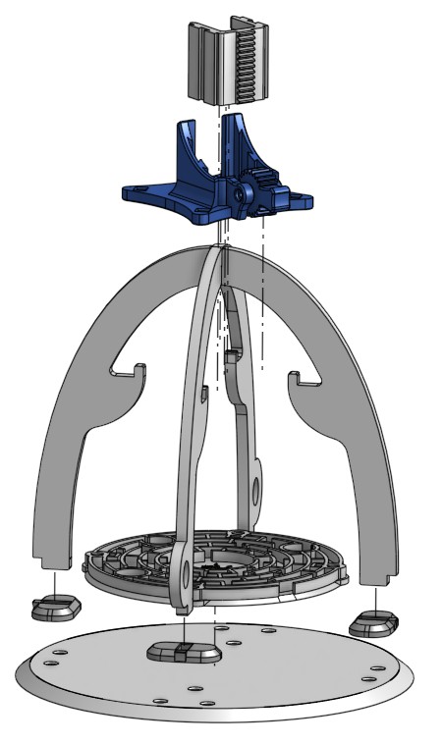
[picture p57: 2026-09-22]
3D Printed Files/Render/Exploded View.jpg

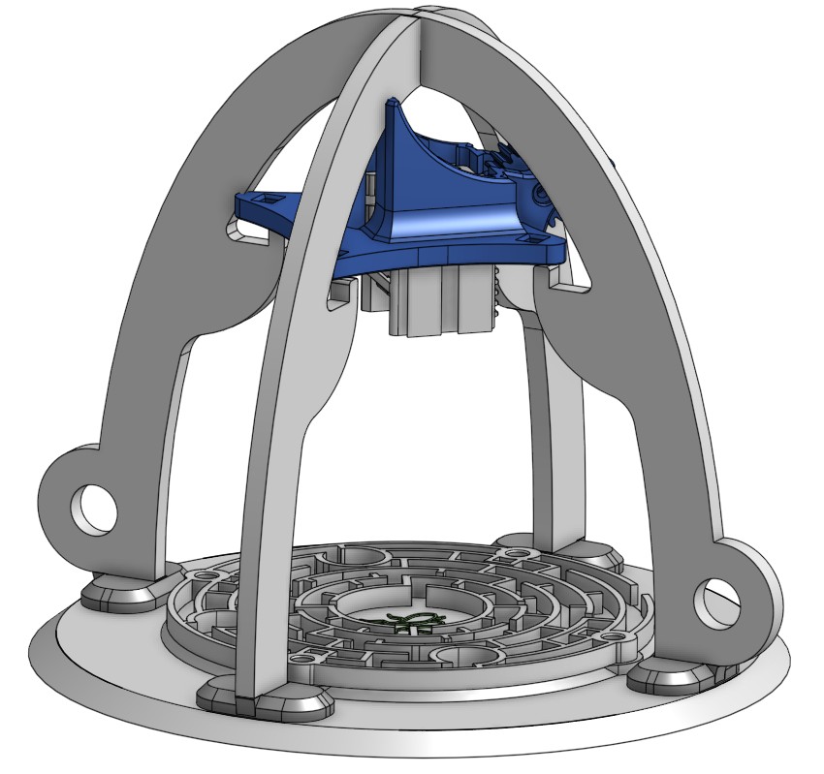
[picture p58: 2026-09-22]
3D Printed Files/Render/Image-001.jpg

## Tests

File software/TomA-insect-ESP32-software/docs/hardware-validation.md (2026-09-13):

# Hardware validation record

Update this record as evidence is collected. SD endurance and final cadence validation remain outstanding. A formal one-hour battery-capacity profile is no longer required for this pilot because the expected one-hour load is comfortably within a standard USB battery pack; retain a short stability and clean-power-removal smoke test using the intended pack.

| Check | Required evidence | Result |
| --- | --- | --- |
| Board | ESP32-S3R8 XIAO ESP32S3 Sense; clean PlatformIO build and upload | Verified on physical board (COM4). Independently reproduced 9 September 2026 on a second, clean Windows 10 machine with no prior toolchain: `git clone` → `py -m pip install platformio` → `py -m platformio run` → upload → boot evidence → 1 FPS QXGA capture → clean `dev_bridge_client.py stop`. Setup-doc gaps found in that run are fixed in [setup-guide.md](setup-guide.md) / [next-session.md](next-session.md). |
| Camera | OV3660 PID reported at boot | Verified at boot |
| PSRAM | `psramFound()` succeeds | Verified at boot |
| SD | FAT32 card mounts and survives 3,600 QXGA writes | Two independent one-hour endurance runs, 28 August 2026: dark (`run_000041`, 3,589/3,600) and daylight (`run_000050`, 3,585/3,600). Both self-finished cleanly, no reboot, no storage error, no corruption. **Neither hit the exact 3,600 target** - see finding below; the shortfall is confirmed present regardless of lighting/JPEG size. Historical run 000012 retained 2,384 smaller JPEGs in 24 bounded shards; completed QXGA run 000004 retained 120 images. Card corruption observed once after normal battery-cable removal; see incident below. |
| Capture | QXGA/JPEG-quality-12 frame every 1,000 ms | Dark run: 3,589/3,600 (99.7%). Daylight run: 3,585/3,600 (99.6%), `interval_mean_ms=1004`, `interval_max_ms=2363`. No reboot/crash in either. Completed QXGA run 000004 captured 120 images at a 1,000 ms median interval. QXGA/2-FPS was rejected (171/240 images; write time exceeded its budget). **Image-quality review done 28 August 2026** (daylight, `run_000050`) - see finding below: soft focus throughout, exposure acceptable, a colour-balance issue at session start that clears within ~30 minutes (a fix was attempted 28-29 August 2026; it did not resolve the issue - see finding below). |
| Battery | Intended USB pack powers a representative capture run without reset, unsafe heating, or storage corruption; normal cable removal recovers cleanly | The 28 August one-hour run stayed powered throughout with no reset, but was not a deliberate power-removal/stability test - board was already on external USB power for unrelated remote-work reasons. Short stability smoke test with the *intended* pack, plus clean-removal recovery, remains pending; formal capacity profiling deprioritised by owner |
| Recovery | Power interruption preserves prior CSV/chunks and marks the run interrupted | Verified with battery disconnect and subsequent reboot. Run 000012 awaits its next card-in-board boot to receive its normal `interrupted_power_removed` state. |
| Dashboard | Opens offline in Chrome, Edge, Firefox, Safari; images and full chunk index load | Verified locally in the SD-card dashboard; full browser matrix pending. Front-page metrics reworked 29 August 2026 (images, last-session duration, picture size, storage remaining - the last held back, see finding below) and the AI-availability note corrected. The storage-remaining tile was later replaced outright (12 September 2026, see docs/next-session.md) rather than left waiting on the firmware fix below. |

## Verified: one-command new-device setup, fresh board + fresh card (10 September 2026)

First end-to-end run of `py tools\setup_device.py` on hardware that had never been
set up before: a new XIAO ESP32S3 Sense and a blank 8 GB FAT32 microSD card.

- **Firmware step:** board auto-detected on `COM5` (Espressif USB VID), built and
  uploaded via the wrapped `py -m platformio run -e xiao_esp32s3 -t upload`. Boot
  evidence confirmed PSRAM, OV3660, SD mount, null inference.
- **Card step:** `prepare_card()` installed the dashboard, `vendor/mediabunny.min.cjs`
  (650,512 bytes, byte-exact), blank runtime files, the pilot `config.json`, and the
  `images/ raw/ data/ system/` folders. Re-run confirmed idempotent.
- **Capture test** (`run_000001`, ended via the Wi-Fi control app's Finish button,
  audited over the [dev bridge](dev-bridge.md)): run state `finished` (clean, not
  interrupted); 46/46 images, one shard, **0 temp/partial files**; every CSV row
  `2048 x 1536`, `outcome=completed`, `save_outcome=saved`; `interval_mean_ms=996`,
  `interval_max_ms=1005`; first retained frame at uptime 16.5 s (after the 15 s AWB
  warm-up); `manifest.js` / `summary.js` both agree with the 46-row CSV.

Full chain works: flash -> card prep -> boot -> config load -> QXGA capture -> safe
stop -> internally consistent data. `GET` of `captures.csv` over the dev bridge
still needed retries (known USB-CDC transfer bug, not a card fault; on-device
`AUDIT` confirmed the file intact).

## Finding: `SD.totalBytes()` reports a wrong value on every normal (cold) boot (29 August 2026)

Found while adding a storage-remaining metric to the dashboard front page. `SdStorage::totalBytes()` (a thin wrapper over `SD.totalBytes()`) reports a value roughly double the card's actual capacity (`7,948,206,080` vs. the correct `3,653,238,784`, confirmed via the dev-bridge `DF` command on the same physical mount) - but only on the **very first `SD.begin()` call since power-on**. Any later, separate `SD.begin()` call in the same power cycle (e.g. the dev-bridge's `MOUNT` command, run after a session has stopped) reports correctly. The wrong value is stable for the entire session, not just the initial read - re-checked after a chunk promotion (~100 captures in) with no change. `SD.usedBytes()` is unaffected throughout.

Three fixes tried, all firmware-only, none successful - recorded so they are not retried without new information:
1. **Not an SPI clock effect.** Both the wrong cold-mount reading and the correct warm-mount reading were confirmed at the same negotiated 25 MHz.
2. **A throwaway `SD.begin()`/`SD.end()` cycle before the real mount** (hypothesis: "warm up" the reporting without changing real mount behaviour) - no effect, value unchanged.
3. **`SD.cardSize()` instead of `SD.totalBytes()`** - a completely different code path (`sdcard_num_sectors()`/`sdcard_sector_size()`, reading the card's own registers, versus `totalBytes()`'s `f_getfree()` call into FATFS volume metadata) - reproduced the identical wrong value. This is the most informative negative result: it points at the underlying SD driver's own card-geometry detection being wrong on a cold mount, not at anything in the Arduino-level FAT filesystem layer, which is beyond what could be safely investigated further without lower-level ESP-IDF tooling or physical access.

**Practical impact:** every normal deployment reads this value from a cold boot - nobody naturally triggers a second `SD.begin()` before looking at the dashboard - so this would be wrong in every real use case, not an edge case. The dashboard's storage-remaining metric was built and worked correctly end-to-end, but `DashboardWriter::writeSummary()` deliberately did not populate `sdTotalBytes`/`sdUsedBytes` until this was fixed, rather than ship a number known to be wrong. **Superseded 12 September 2026:** rather than leave the tile reading "Soon" indefinitely, it was replaced with a total-recorded-time metric derived from capture timestamps instead - see docs/next-session.md. The firmware bug itself is unchanged and still unfixed; only the dashboard-side placeholder is gone. Left as an open firmware/driver-level investigation for whoever has the tooling to go deeper (live heap/register debugging, or checking whether this is a documented erratum for this card/ESP-IDF SD driver combination).

## Incident: FAT32 root-directory corruption after normal power-off (21 August 2026)

After a successful motion-mode test run (`run_000002`, the shard-directory fix validation — 299 checks, 31 saved images, 0 storage errors during capture), the card was stopped normally by disconnecting the battery cable and moved to a card reader. On the next mount, Windows reported the volume as a healthy FAT32 filesystem (correct size, no dirty bit), but the root directory itself was corrupted: every real file and folder (`dashboard.html`, `config.json`, `raw/`, `images/`, `data/`, `system/`) had been replaced by a single garbled, zero-length pseudo-entry that both `attrib` and PowerShell's file APIs treated as a broken symbolic link.

This is first-hand confirmation of the FAT32 write-safety risk already flagged in `docs/next-session.md` and the project brief: the filesystem's own directory/FAT metadata is not written atomically, and the documented stop method (disconnect the battery cable) gives no opportunity for a controlled unmount. The firmware's per-frame atomic-rename writes protected individual images and CSV rows during the session itself (no corruption was ever observed while captures were running, across today's session or the prior one), but this incident shows the risk sits one level up, in the filesystem's own directory table, which firmware-level write discipline cannot fully protect against.

Recovery attempted: `chkdsk /f` repaired the volume and recovered 2,007 orphaned cluster fragments (275 MB) into `FOUND.000`. 1,913 of those fragments began with a valid JPEG signature, so most of the recovered data was genuine photo content, but the recovery was fragment-level (unordered ~32 KB clusters, most JPEGs span several), carried no filenames or session metadata, and only one fragment retained readable `captures.csv` header text. Given the run was this week's test data rather than irreplaceable field data, reconstruction was not attempted; the card was reformatted clean instead.

**Open follow-up:** this remains an unresolved hardware-level gap, not something firmware alone can fully close (see the physical power hold-up circuit note in the project brief). It also means a corrupted card is a real, observed failure mode for the pilot, not just a theoretical one — worth factoring into the one-hour endurance test and any operator-facing guidance on stopping the camera safely.

## Finding: one-hour pilot runs consistently fall ~10-15 images short of 3,600; dark-scene-JPEG-size theory tested and not confirmed (28 August 2026)

**Dark run** (`run_000041`), driven entirely over the serial [dev bridge](dev-bridge.md) while unattended: the card had drifted to a stale 5-minute trial `config.json` (`max_session_seconds: 300`) from earlier testing, corrected to the repository pilot default and applied with `reboot`. Ran its full `max_session_seconds: 3600`, self-finished cleanly, no reboot/storage error/corruption. **Captured 3,589/3,600** - 35 full shards plus a partial final shard (89 images). Averaged ~190 KB/image, well above the ~87 KB reference, in a dark room. Working theory at the time: larger, noisier dark-scene JPEGs push some per-frame writes over the 1,000 ms budget, and the schedule never fully catches up over an hour.

**Daylight run** (`run_000050`), same protocol, run after the room had light again: **captured 3,585/3,600** - *slightly worse*, not better, despite JPEGs averaging 87,656 bytes (right on the ~87 KB reference, confirming lighting was the reason the dark run's files were oversized). `interval_mean_ms=1004` (on target) but `interval_max_ms=2363` - a *larger* worst-case gap than the dark run's 2,085 ms. Both runs' stats came from the on-device `AUDIT` command (see [dev-bridge.md](dev-bridge.md)), which also confirmed `csv_completed` exactly matches the on-disk image count in both cases - the shortfall is real capture loss, not a logging/audit discrepancy.

**Conclusion: the dark-scene-JPEG-size theory is not confirmed.** Smaller files did not close the gap or reduce the worst-case interval - if anything both got slightly worse. The ~0.3-0.4% shortfall looks like a more fundamental, lighting-independent cadence issue (`AUDIT` only reports mean/max interval, not the full distribution or its correlation with individual frame write time, so the exact mechanism - occasional SD/filesystem housekeeping cost, chunk-promotion overhead, or something else - remains open). Worth revisiting once the write-path reduction work in `next-session.md`'s SD-performance section has progressed further, or with finer-grained per-frame instrumentation than `AUDIT` currently provides.

## Finding: image-quality review, daylight run 28 August 2026 (`run_000050`)

Two real JPEGs pulled from the card and viewed directly (`shard_0001/..._img_1.jpg`, session start; `shard_0019/..._img_1850.jpg`, ~31 minutes in), subject a printed photo of ants placed under the camera, viewed top-down through the enclosure's corner mounts:

- **Focus:** Soft throughout both images, consistently - the enclosure's own corner brackets are equally soft, so this reads as a fixed-focus/depth-of-field characteristic at this camera-to-subject distance, not something specific to the subject or session timing.
- **Exposure:** Acceptable in both, not blown out or underexposed, though slightly flat/low-contrast.
- **Colour - a real finding:** `img_1` (session start) has a distinct **green/cyan colour cast** across the whole frame. `img_1850` (~31 minutes later) is close to neutral white/grey. This looks like auto-white-balance settling in over the first part of a session rather than a fixed characteristic - worth checking whether this affects data quality specifically in the first few minutes of every run, and whether it's consistent enough to warn about or correct for.
- **Small-insect detail:** Ant body outlines are identifiable in both images, but fine features (legs, antennae) are not resolved at this quality/distance. **Caveat:** the subject was a printed photo, not live insects, so print quality is a real confound here - this is not a clean test of live small-insect detail capture, which still needs doing.

## Fix attempted: session-start white balance - did not resolve it (28 August-29 August 2026)

The user reported the session-start green cast (finding above) as a repeated problem, not a one-off. Investigating `src/camera_service.cpp` found the driver never explicitly configured AWB, relying entirely on `esp_camera_init()` defaults, and `src/main.cpp`'s 5-second camera warm-up was a bare `delay(kCameraWarmupMs)` - the sensor was never actually asked to produce a frame during that window. AWB/AEC algorithms converge on captured frames, not elapsed time, so a pure delay gives them zero iterations to work with; this is a strong candidate for why 5 seconds did nothing but ~1,800 real captures (30 minutes at 1 FPS) did.

**Fix:** `CameraService::initialiseCamera()` now explicitly calls `set_whitebal(1)`, `set_awb_gain(1)`, `set_wb_mode(0)` (auto, not a fixed preset) after every sensor init, and exposes `whiteBalanceStatus()` for boot-log diagnostics. `setup()`'s warm-up (`kCameraWarmupMs`, now 15,000) replaced the bare `delay()` with an active loop that calls `camera.capture()`/`camera.release()` repeatedly until the deadline, giving AWB/AEC real frames to converge on before the first frame is ever retained. Costs nothing against the 3,600 s capture budget - `session_started_ms` is only set after warm-up completes.

**Functionally verified 28 August 2026** (smoke test only, not a colour-quality trial - it was evening): built, flashed, and the boot log confirmed the mechanism works as intended - `awb=1 awb_gain=1 wb_mode=0` both before and after warm-up, and **85 real frames pumped** in 15 s (versus zero previously). A short test session then captured normally with no crashes, no dropped frames, clean stop.

**Daylight trial run 29 August 2026, ~09:00-09:45.** Two independent sessions on the fixed firmware, both fully unattended over the dev bridge:

- **Trial 1** (`run_000053`, ~5 minutes): `img_1` (session start) and `img_320` (~5 min in) both showed the same **purple/magenta cast**, visually unchanged between the two - inconclusive on its own, so the trial was extended rather than concluded from 5 minutes.
- **Trial 2** (`run_000054`, ~30 minutes, matching the timeframe that showed clearing before the fix): `img_1` again showed the purple/magenta cast; `img_1650` (~27 minutes in) was **neutral white/grey** - the cast had cleared, on essentially the same timeline as before this fix (previously ~30 minutes for a green cast).

**Conclusion: the fix did not solve the problem, though its own mechanism worked exactly as designed.** The boot log confirmed correct AWB configuration and 85 real frames pumped during the 15 s warm-up (see below) - a substantial improvement over zero, but evidently still nowhere near enough for AWB to reach a converged state before the first retained frame. The cast is still present at session start, still takes on the order of ~30 minutes to clear, and - a new observation - **the cast's actual colour is not fixed**: green on 28 August, purple/magenta on both 29 August trials. That variability suggests whatever state AWB starts from at boot is itself inconsistent, not a single deterministic offset that a modest, fixed warm-up could reliably correct for.

**Not attempted further on 29 August, left as concrete next steps for whoever picks this up:**
1. Query `sensor_->status.awb_gain`/`aec_value`/related register fields at boot and periodically during a session (not just the on/off flags already logged) to see the actual convergence trajectory, rather than inferring it indirectly from JPEG output. Still not attempted - the ESP-DL/esp32-camera source needed to confirm OV3660's actual gain register addresses isn't vendored into this project (headers only, no driver `.c` source), and guessing register numbers to `get_reg`/`set_reg` against real hardware was judged too risky to try blind.
2. Consider a much longer active warm-up - real convergence takes roughly 1,600-1,800 real frames (~27-30 minutes at 1 FPS) based on both this and the prior finding, two orders of magnitude more than the 85 frames tried here. A warm-up that long is a real operational cost (delays the effective start of every session, even though it doesn't shrink the 3,600 s capture budget itself) and would need a product decision, not just an engineering one.
3. Consider seeding AWB from a fixed, pre-calibrated gain for typical enclosure conditions rather than relying on cold-start auto-convergence at all - trading some adaptability for a much faster, more predictable start.
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

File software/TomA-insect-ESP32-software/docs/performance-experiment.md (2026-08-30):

# Performance experiment

> Historical record: the 2-FPS/VGA experiments below led to the current directory-sharding implementation. On 17 August 2026 the pilot setting was changed to QXGA/JPEG-quality-12/1-FPS after the dedicated quality trials: QXGA at 1 FPS completed cleanly, while QXGA at 2 FPS captured only 171 of 240 expected images. The active acceptance protocol is now in [camera-quality-trial.md](camera-quality-trial.md).

## SD clock speed raised to 25 MHz (27 August 2026)

Prompted by a collaborator suggesting exFAT for write throughput. Investigating that surfaced a cheaper lever first: `SD.begin(pin)` uses the arduino-esp32 default of **4 MHz SPI**, which we had never overridden.

`SdStorage::begin()` now tries **25 → 20 → 10 → 4 MHz** and keeps the first clock the card mounts at. The ladder matters because a kit shipped to schools meets cards of unknown age; a card that will not take 25 MHz still works, only slower, rather than failing to mount. The achieved clock is reported in the boot diagnostic and recorded in a new `sd_clock_hz` column in the performance CSV, so runs document their own conditions.

**Measured effect** — `run_000032`, QXGA/quality-12/1-FPS, retain every frame, ~98 KB frames. Baseline is runs 000001–000003 at the 4 MHz default:

| | 4 MHz (baseline) | 25 MHz (`run_000032`) |
| --- | --- | --- |
| `image_write_ms` | 758–777 | **382–405** |
| Effective throughput | ~129 KB/s | **~244 KB/s** |

Image write time roughly halved. The card accepted the top rung, so no fallback occurred.

### The bottleneck has moved from the bus to metadata

244 KB/s against a 25 MHz bus is roughly 8% utilisation, so further clock increases have little left to give. Per-frame cost at the sampled frames:

- image write **405 ms**
- raw CSV append **112 ms**
- dashboard chunk **447 ms**
- **total 983–1030 ms** against a 1,000 ms budget at 1 FPS

Metadata logging now costs more than writing the JPEG itself: a ~250-byte text line is more expensive than a 99 KB image, because every append is a separate open/write/flush/close and FAT must update the directory entry, the FAT, and the data cluster each time.

**On exFAT:** the original suggestion has merit — exFAT's allocation bitmap and single FAT would reduce exactly this metadata cost. It is not available in our toolchain, though: the arduino-esp32 prebuilt ESP-IDF ships with `FF_FS_EXFAT 0` and no exFAT symbols in `libfatfs.a`, so an exFAT card would not mount. Adopting it means either rebuilding ESP-IDF (an ADR-level change per the project brief) or replacing `SD.h` with SdFat. Worth revisiting only after the leaner write path, since the measurements say our own write pattern is the larger share.

### Measurement artifact: sampling aligns with chunk promotion (fixed 28 August 2026)

`kPerformanceSampleInterval` was 100 and `DashboardWriter::kChunkSize` is also 100, so **every performance sample landed exactly on a chunk promotion** — a rename plus `saveState`, `writeManifest` and `writeSummary`. The `dashboard_ms` figures above were therefore worst-case, not typical, and no ordinary frame had ever been sampled.

**Fixed:** `kPerformanceSampleInterval` changed to **97** (a prime, so it can never land on a multiple of the 100-frame chunk cycle) in `src/main.cpp`. Verified live: rebooted, let a short test session run past capture 97, then read its performance log directly over the [dev bridge](dev-bridge.md) (`cat /system/performance_run_000049.csv`) rather than guessing the fix worked:

```
capture_id,...,image_write_ms,raw_csv_ms,dashboard_ms,logger_ms,total_ms,jpeg_bytes,...
run_000049_img_97,...,393,291,26,318,732,85910,...
```

Sample landed on capture 97 as intended, and `dashboard_ms` is **26 ms** - not the 447 ms chunk-promotion figure above. `total_ms` is 732 ms, comfortably under the 1,000 ms budget. This is the first genuinely typical-frame measurement on record; the 983–1,030 ms figures above remain accurate as the *chunk-promotion* cost, just not as the steady-state cost, which was the actual point of this fix.

### Also observed

`capture_ms` fell from ~224 ms to **1 ms**. Retain-every-frame mode leaves the camera streaming, whereas motion mode reinitialises the sensor at each grayscale/JPEG switch. That ~224 ms is a previously unisolated cost of motion mode.

### Next steps

1. ~~Decorrelate the performance sampling interval from the chunk size, then re-measure to get honest steady-state figures.~~ Done 28 August 2026, see above. One sample confirmed the fix works; a longer run would give a proper distribution rather than a single data point.
2. Reduce the write path, in likely order of payoff: chunk promotion performing four file operations at once; three separate files opened and closed per frame; and the atomic write's `remove` → `open` → `write` → `flush` → `close` → `rename`.
3. Reconsider exFAT only if metadata cost still dominates afterwards.

## Purpose

The first one-hour run completed safely but slowed from roughly 0.9 seconds per frame at the beginning to roughly 5.5 seconds per frame at the end. This experiment identifies whether the growth comes from camera capture, image writes, raw/dashboard logging, or heap fragmentation.

The default capture behavior is unchanged: every scheduled attempt is retained in `/raw/captures.csv`, every successful JPEG is retained, and the null inference adapter remains active.

## Instrumentation

The firmware writes one bounded diagnostic sample for every 100 capture attempts to:

```text
/system/performance_<run-id>.csv
```

It records:

- capture ID and scheduled time;
- start lateness;
- camera capture duration;
- JPEG write duration;
- separate raw CSV and dashboard stage durations;
- total frame-processing duration;
- JPEG size and outcome;
- free heap, largest free heap block, minimum free heap;
- free PSRAM and largest free PSRAM block.

The diagnostic file is not authoritative and is not loaded by the dashboard. It is retained for the experiment and can be removed manually after backup.

## Run protocol

1. Back up the SD card or create a read-only card image before testing.
2. Confirm the card contains `config.json`, and set `max_session_seconds` to a short test duration such as 600 seconds for development runs. Keep `capture_fps` at `2`.
3. Upload the instrumented firmware:

   ```powershell
   py -m platformio run -e xiao_esp32s3 -t upload --upload-port COM4
   ```

4. Insert the backed-up card into the powered-off camera and run one controlled test. Disconnect the battery cable to stop it; never remove the card while powered.
5. Run the read-only audit after transfer:

   ```powershell
   py tools\audit_card.py D:\
   ```

6. Copy `/system/performance_<run-id>.csv` off the card and compare the first, middle, and final samples. Do not use the dashboard count alone to judge throughput.
7. Repeat with a fresh copied card if a second run is needed. Keep the original experiment card unchanged.

## Interpretation

- If `image_write_ms` grows while capture and logger times stay stable, investigate FAT directory growth, file fragmentation, card quality, and the atomic image-write sequence.
- If `logger_ms` grows, investigate raw CSV append, dashboard append, repeated open/flush/close, and `String` allocation.
- If free heap or largest free heap block declines steadily, investigate heap fragmentation and temporary `String` objects.
- If camera `capture_ms` grows while storage timings remain stable, investigate camera buffering, sensor state, or thermal behavior.
- If all stage times remain stable but intervals still grow, inspect scheduler lateness and delay/rebase behavior.

## Follow-up isolation tests

Only after the instrumented full-pipeline run is backed up should we create test-only firmware variants that omit one derived output at a time. These variants must never be used for field data collection:

1. image plus raw CSV, dashboard chunks disabled;
2. image plus dashboard chunks, raw CSV disabled;
3. image write only.

Each variant must retain serial warnings that it is test-only and must be run on a copied card. The full-pipeline firmware remains the acceptance configuration.
## First instrumented result: run_000010

The ten-minute diagnostic run was stopped by the normal battery disconnect, so its run manifest remains `running` and one final `.tmp` image is expected. The run produced 483 completed image records before removal.

| Sample | Image write | Logger | Total | Start lateness |
| --- | ---: | ---: | ---: | ---: |
| Frame 100 | 560 ms | 703 ms | 1,263 ms | 294 ms |
| Frame 200 | 924 ms | 709 ms | 1,633 ms | 510 ms |
| Frame 300 | 1,300 ms | 739 ms | 2,040 ms | 880 ms |
| Frame 400 | 1,705 ms | 749 ms | 2,454 ms | 1,268 ms |

Camera capture remained below the millisecond resolution of the current timer, and free heap/free PSRAM stayed constant. The evidence therefore localises the progressive slowdown to the JPEG write path, not camera capture or accumulating heap allocations. The next isolation test should compare the current atomic image write against a direct final-path write on a copied card, then compare one large run directory with sharded image directories. Direct-write firmware is test-only and must not be used for retained field data.
## Optimized run result: run_000011

The logger/JPEG optimization was tested on the same card. The run was stopped after approximately ten minutes by battery removal and produced 608 completed records.

| Sample | Previous image write | Optimized image write | Previous logger | Optimized logger | Previous total | Optimized total |
| --- | ---: | ---: | ---: | ---: | ---: | ---: |
| Frame 100 | 560 ms | 498 ms | 703 ms | 1,120 ms | 1,263 ms | 1,637 ms |
| Frame 200 | 924 ms | 796 ms | 709 ms | 1,107 ms | 1,633 ms | 1,945 ms |
| Frame 300 | 1,300 ms | 1,182 ms | 739 ms | 1,108 ms | 2,040 ms | 2,488 ms |
| Frame 400 | 1,705 ms | 1,442 ms | 749 ms | 1,125 ms | 2,454 ms | 2,588 ms |
| Frame 600 | ??? | 2,055 ms | ??? | 1,122 ms | ??? | 3,226 ms |

The average interval changed only from 1,292 ms in run_000010 to 1,265 ms in run_000011, despite the logger changes. Image writes were modestly faster at comparable early samples but still grew with accumulation. Logger time increased to about 1.1 seconds, so keeping the files open with a flush on every row is not an improvement on this SD/FAT stack. The optimization should not be treated as accepted.

Because only one card is available, this is not a clean isolated A/B test: the card contains more files than during run_000010, and JPEG sizes vary. The next implementation should revert or redesign the open-handle logger path, then instrument raw CSV append, dashboard append, and chunk promotion as separate sub-stages. The image path needs a directory-sharding experiment or a preallocation/append design rather than more metadata checks around the same per-image atomic write.

## Next diagnostic build: run_000012 preparation

The open-handle logger change from run_000011 was rejected: logger time rose to about 1.1 seconds per frame. The next build restores the safer per-row append behaviour and records the two logger sub-stages separately as `raw_csv_ms` and `dashboard_ms` in `/system/performance_<run-id>.csv`.

New JPEGs are written beneath `/images/<run-id>/shard_0001/`, then `shard_0002/` after each 100-frame boundary. This keeps each FAT directory bounded while preserving the authoritative raw CSV and dashboard paths. The atomic create-and-rename write is retained for power-loss safety.

For the next test, use the same ten-minute, 2 FPS protocol on the available card. After disconnecting the battery and mounting the card, compare `image_write_ms`, `raw_csv_ms`, `dashboard_ms`, and `logger_ms` at frames 100, 200, 300, and 400. Also check that each shard contains no more than 100 JPEGs, every raw row points to an existing image or an explicitly recorded save failure, and the dashboard count includes all closed chunks plus the recovered current chunk.

## Storage milestone: run_000012

Run 000012 tested the revised per-row logger together with 100-image JPEG directory shards. It produced 2,384 completed captures before the normal battery disconnect. The run-relative records, dashboard data, and retained JPEGs all agree: 2,384 records, 2,384 dashboard entries, and 2,384 JPEGs across `shard_0001` through `shard_0024`. The one final `.tmp` file is the interrupted atomic write expected at power removal.

| Sample | Image write | Raw CSV | Dashboard | Logger | Total |
| --- | ---: | ---: | ---: | ---: | ---: |
| Frame 100 | 530 ms | 55 ms | 802 ms | 857 ms | 1,387 ms |
| Frame 1,000 | 652 ms | 64 ms | 1,305 ms | 1,370 ms | 2,023 ms |
| Frame 2,300 | 546 ms | 73 ms | 814 ms | 888 ms | 1,435 ms |

This accepts directory sharding as the effective mitigation for the progressive JPEG-write slowdown: comparable earlier runs rose from about 500 ms to more than 1.7 or 2.0 seconds, whereas this run remained close to 0.55 seconds across 2,300 samples. Raw CSV and dashboard times were also broadly stable, aside from the isolated frame-1,000 dashboard outlier.

Do not yet treat the absolute capture cadence as accepted. The final raw row is at 1,340,538 ms for capture 2,384, which suggests roughly 1.78 frames per second, but the sampled `total_ms` values are usually about 1.4 seconds and cannot coexist with that elapsed time. The next firmware change must validate duration measurement with an independent monotonic source and record a per-frame consistency check before another rate conclusion is made.

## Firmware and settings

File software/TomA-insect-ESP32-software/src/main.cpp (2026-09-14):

#include <Arduino.h>
#include <esp_heap_caps.h>

#include "app_config.h"
#include "camera_service.h"
#include "control_server.h"
#include "dev_bridge.h"
#include "inference.h"
#include "motion_detector.h"
#include "sd_storage.h"
#include "session_logger.h"

namespace {
AppConfig config;
SdStorage storage;
CameraService camera;
NullInferenceEngine inference;
SessionLogger logger;
ControlServer control_server;
DevBridge dev_bridge;

bool ready = false;
bool finished = false;
uint32_t next_capture_due_ms = 0;
uint32_t session_started_ms = 0;
uint32_t saved_image_count = 0;
String fatal_error;
// Stable identifier for the phone app's translation table - see the
// storage-mount-failure branch below. Empty for every other fatal_error,
// which the app still shows via fatal_error itself, untranslated.
String fatal_error_code;
MotionPreview previous_motion_preview;
MotionPreview current_motion_preview;
bool motion_baseline_ready = false;
// Deliberately prime and not 100: DashboardWriter::kChunkSize is 100, and an
// equal interval meant every performance sample landed exactly on a chunk
// promotion (a rename plus saveState/writeManifest/writeSummary), so every
// figure ever recorded was worst-case rather than typical. See
// docs/performance-experiment.md.
constexpr uint32_t kPerformanceSampleInterval = 97;
// History: was a bare delay(5000), which gave AWB/AEC no captured frames
// to iterate on. Two active-pump designs followed (see
// docs/hardware-validation.md "Fix attempted"/"Seeded white balance" for
// the full trail) before landing here. 31 August 2026: seed AWB directly
// via CameraService::seedWhiteBalance() (real OV3660 register writes,
// confirmed from driver source, not guessed) with a value measured from
// this room's actual lighting, then pump briefly in the real capture mode
// so AWB walks from that seed to whatever's optimal right now, rather than
// racing cold auto-convergence from the hardware's 1024/1024/1024 default.
// No sensor-mode switch happens in this design (a real bug in the prior
// attempt: every esp_camera_init() call resets manual gain to
// 1024/1024/1024, so warming up in a different mode and switching back
// threw the whole thing away) - the seed is written directly onto the
// already-configured capture sensor. Measured convergence with no reset in
// the way plateaus within ~10 s (57 frames); kept some margin above that.
constexpr uint32_t kCameraWarmupMs = 12000;
// Measured 31 August 2026 (run_000078, this room, daylight): AWB converges
// to approximately this gain and produces a visually neutral image within
// ~10 s of continuous pumping with no sensor reset. Used as a starting
// point, not a locked value - seedWhiteBalance() hands control straight
// back to auto AWB, which keeps adjusting for whatever the light actually
// is when the device boots. If the camera moves to a different location or
// lighting, expect the *speed* of settling to matter less than usual (it's
// already close) but the seed itself may need remeasuring for a very
// different environment - see docs/hardware-validation.md "Seeded white
// balance" for how these were found and how to redo it.
constexpr uint16_t kWhiteBalanceSeedRedGain = 1055;
constexpr uint16_t kWhiteBalanceSeedGreenGain = 1024;
constexpr uint16_t kWhiteBalanceSeedBlueGain = 2100;

struct CaptureTiming {
  uint32_t scheduled_ms = 0;
  uint32_t start_lag_ms = 0;
  uint32_t capture_ms = 0;
  uint32_t image_write_ms = 0;
  uint32_t raw_csv_ms = 0;
  uint32_t dashboard_ms = 0;
  uint32_t logger_ms = 0;
  uint32_t total_ms = 0;
  size_t jpeg_bytes = 0;
  String outcome;
};

String performance_path;

float motion_history[ControlStatus::kMotionHistoryCapacity] = {};
uint8_t motion_history_count = 0;
uint8_t motion_history_next = 0;

void recordMotionScore(float score) {
  motion_history[motion_history_next] = score;
  motion_history_next = (motion_history_next + 1) % ControlStatus::kMotionHistoryCapacity;
  if (motion_history_count < ControlStatus::kMotionHistoryCapacity) ++motion_history_count;
}

void report(const String& message) { Serial.println("[insect-logger] " + message); }

String imageDirectoryFor(uint32_t sequence) {
  char shard[16];
  snprintf(shard, sizeof(shard), "shard_%04lu", static_cast<unsigned long>(((sequence - 1) / 100) + 1));
  return "/images/" + logger.runId() + "/" + String(shard);
}

String imagePathFor(const String& capture_id, uint32_t sequence) {
  return imageDirectoryFor(sequence) + "/" + capture_id + ".jpg";
}

void recordCaptureFailure(const String& capture_id, uint32_t scheduled_ms, const String& error_code) {
  CaptureRecord record;
  record.capture_id = capture_id;
  record.uptime_ms = millis();
  record.scheduled_ms = scheduled_ms;
  record.outcome = "capture_error";
  record.save_outcome = "not_attempted";
  record.error_code = error_code;
  String diagnostic;
  if (!logger.recordCapture(record, diagnostic)) report("failed to log capture error: " + diagnostic);
}

bool refreshMotionBaseline(String& diagnostic) {
  // Reinitialising the OV3660 after a JPEG changes auto exposure for its first
  // grayscale frames. Discard two of them, then compare future scheduled checks
  // against the settled preview rather than the pre-JPEG image.
  if (!camera.captureMotionPreview(current_motion_preview, diagnostic)) return false;
  if (!camera.captureMotionPreview(previous_motion_preview, diagnostic)) return false;
  motion_baseline_ready = true;
  return true;
}

void ensurePerformanceLog() {
  if (performance_path.isEmpty() || storage.exists(performance_path)) return;
  String diagnostic;
  const String header =
      "capture_id,scheduled_ms,start_lag_ms,capture_ms,image_write_ms,raw_csv_ms,dashboard_ms,logger_ms,total_ms,jpeg_bytes," \
      "outcome,free_heap,largest_free_heap,min_free_heap,free_psram,largest_free_psram,sd_clock_hz";
  if (!storage.appendLine(performance_path, header, diagnostic)) report("performance log unavailable: " + diagnostic);
}

void writePerformanceSample(const String& capture_id, const CaptureTiming& timing) {
  if (logger.captureCount() % kPerformanceSampleInterval != 0) return;
  const uint32_t free_heap = ESP.getFreeHeap();
  const uint32_t largest_free_heap = heap_caps_get_largest_free_block(MALLOC_CAP_8BIT);
  const uint32_t min_free_heap = ESP.getMinFreeHeap();
  const uint32_t free_psram = ESP.getFreePsram();
  const uint32_t largest_free_psram = heap_caps_get_largest_free_block(MALLOC_CAP_SPIRAM);
  const String line = capture_id + "," + String(timing.scheduled_ms) + "," +
      String(timing.start_lag_ms) + "," + String(timing.capture_ms) + "," +
      String(timing.image_write_ms) + "," + String(timing.raw_csv_ms) + "," +
      String(timing.dashboard_ms) + "," + String(timing.logger_ms) + "," +
      String(timing.total_ms) + "," + String(static_cast<unsigned long>(timing.jpeg_bytes)) + "," +
      timing.outcome + "," + String(free_heap) + "," + String(largest_free_heap) + "," +
      String(min_free_heap) + "," + String(free_psram) + "," + String(largest_free_psram) + "," +
      String(storage.clockHz());
  String diagnostic;
  if (!storage.appendLine(performance_path, line, diagnostic)) report("performance sample write failed: " + diagnostic);
  report("performance sample " + line);
}

CaptureTiming captureOnce(uint32_t scheduled_ms) {
  CaptureTiming timing;
  timing.scheduled_ms = scheduled_ms;
  const uint32_t capture_sequence = logger.captureCount() + 1;
  const String capture_id = logger.nextCaptureId();
  String diagnostic;
  const uint32_t total_started = millis();
  timing.start_lag_ms = total_started - scheduled_ms;
  float motion_score = -1.0F;

  if (config.motion_trigger_enabled) {
    const uint32_t preview_started = millis();
    if (!camera.captureMotionPreview(current_motion_preview, diagnostic)) {
      report(diagnostic);
      recordCaptureFailure(capture_id, scheduled_ms, "motion_preview_unavailable");
      timing.capture_ms = millis() - preview_started;
      timing.total_ms = millis() - total_started;
      timing.outcome = "capture_error";
      writePerformanceSample(capture_id, timing);
      return timing;
    }

    const bool retain = !motion_baseline_ready ||
                        ((motion_score = motionLocalScore(previous_motion_preview, current_motion_preview)) >= config.motion_threshold);
    previous_motion_preview = current_motion_preview;
    motion_baseline_ready = true;
    if (motion_score >= 0.0F) recordMotionScore(motion_score);
    if (!retain) {
      CaptureRecord record;
      record.capture_id = capture_id;
      record.uptime_ms = millis();
      record.scheduled_ms = scheduled_ms;
      record.outcome = "motion_not_detected";
      record.width = kMotionPreviewWidth;
      record.height = kMotionPreviewHeight;
      record.capture_ms = millis() - preview_started;
      record.save_outcome = "not_saved";
      record.motion_score = motion_score;
      record.motion_threshold = config.motion_threshold;
      timing.capture_ms = record.capture_ms;
      const uint32_t logger_started = millis();
      LoggerTiming logger_timing;
      if (!logger.recordCapture(record, diagnostic, &logger_timing)) report("motion log failure: " + diagnostic);
      timing.raw_csv_ms = logger_timing.raw_csv_ms;
      timing.dashboard_ms = logger_timing.dashboard_ms;
      timing.logger_ms = millis() - logger_started;
      timing.total_ms = millis() - total_started;
      timing.outcome = record.outcome;
      writePerformanceSample(capture_id, timing);
      return timing;
    }
    if (!camera.prepareRetainedCapture(diagnostic)) {
      report(diagnostic);
      recordCaptureFailure(capture_id, scheduled_ms, "motion_capture_mode_unavailable");
      timing.capture_ms = millis() - preview_started;
      timing.total_ms = millis() - total_started;
      timing.outcome = "capture_error";
      writePerformanceSample(capture_id, timing);
      return timing;
    }
  }

  const uint32_t capture_started = millis();
  camera_fb_t* frame = camera.capture(diagnostic);
  if (frame == nullptr) {
    report(diagnostic);
    if (config.motion_trigger_enabled) {
      String restore_diagnostic;
      if (!camera.restoreMotionPreview(restore_diagnostic)) report(restore_diagnostic);
    }
    recordCaptureFailure(capture_id, scheduled_ms, "camera_frame_unavailable");
    timing.capture_ms = millis() - capture_started;
    timing.total_ms = millis() - total_started;
    timing.outcome = "capture_error";
    writePerformanceSample(capture_id, timing);
    return timing;
  }

  CaptureRecord record;
  record.capture_id = capture_id;
  record.uptime_ms = millis();
  record.scheduled_ms = scheduled_ms;
  record.width = frame->width;
  record.height = frame->height;
  record.jpeg_bytes = frame->len;
  record.capture_ms = millis() - capture_started;
  record.motion_score = motion_score;
  record.motion_threshold = config.motion_trigger_enabled ? config.motion_threshold : 0;
  timing.capture_ms = record.capture_ms;
  timing.jpeg_bytes = frame->len;
  record.inference = inference.run(*frame);
  record.image_path = imagePathFor(capture_id, capture_sequence);
  if (!storage.ensureDirectory(imageDirectoryFor(capture_sequence), diagnostic)) report(diagnostic);
  record.outcome = "completed";
  record.save_outcome = "saved";

  const uint32_t image_write_started = millis();
  const bool image_saved = storage.writeBinaryAtomicCreate(record.image_path, frame->buf, frame->len, diagnostic);
  timing.image_write_ms = millis() - image_write_started;
  control_server.updatePeek(frame->buf, frame->len);
  camera.release(frame);
  if (config.motion_trigger_enabled) {
    String restore_diagnostic;
    if (!camera.restoreMotionPreview(restore_diagnostic)) {
      report(restore_diagnostic);
      record.error_code = "motion_preview_restore_failed";
    } else if (!refreshMotionBaseline(restore_diagnostic)) {
      report(restore_diagnostic);
      record.error_code = "motion_preview_settle_failed";
    }
  }
  if (!image_saved) {
    record.outcome = "storage_error";
    record.save_outcome = "failed";
    record.image_path = "";
    record.error_code = "image_write_failed";
    report(diagnostic);
  } else {
    ++saved_image_count;
  }
  const uint32_t logger_started = millis();
  LoggerTiming logger_timing;
  if (!logger.recordCapture(record, diagnostic, &logger_timing)) report("capture log failure: " + diagnostic);
  timing.raw_csv_ms = logger_timing.raw_csv_ms;
  timing.dashboard_ms = logger_timing.dashboard_ms;
  timing.logger_ms = millis() - logger_started;
  timing.total_ms = millis() - total_started;
  timing.outcome = record.outcome;
  writePerformanceSample(capture_id, timing);
  return timing;
}

void finishSession() {
  if (finished) return;
  String diagnostic;
  if (!logger.finish(diagnostic)) report("session finalisation failed: " + diagnostic);
  // Unmount unconditionally: even a finaliser failure leaves earlier
  // committed data more likely to survive a clean FAT unmount than none.
  storage.end();
  report("session complete; card unmounted, safe to remove");
  finished = true;
}
}  // namespace

void setup() {
  Serial.begin(115200);
  delay(250);
  report(String("firmware ") + INSECT_LOGGER_FIRMWARE_VERSION + " starting");
  String diagnostic;
  // Wi-Fi starts before any SD/camera/logger step so the control app can
  // still report what went wrong if one of them fails; capture is the
  // primary mission and none of those steps depend on Wi-Fi succeeding.
#ifndef WIFI_CONTROL_DISABLED_FOR_TEST
  if (!control_server.begin(diagnostic)) report("control app unavailable: " + diagnostic);
  else report(diagnostic);
#else
  report("control app disabled for this build: motion-detection control test");
#endif
  if (!storage.begin(diagnostic)) {
    report("fatal storage failure: " + diagnostic);
    // Camera and SD card share the same expansion-board connector (see
    // docs/dev-bridge.md, "Telling a disconnected expansion board apart
    // from a bad SD card") - storage.begin() alone cannot see the camera at
    // all, so on its own this failure is ambiguous between "the board
    // halves aren't connected" and "the card is missing/bad". Probing the
    // camera here - with storage otherwise unreachable - lets the phone
    // app (already up; control_server.begin() ran first for exactly this
    // reason) tell a child/teacher which one they actually have, not just
    // that something failed. A bare default AppConfig is deliberate: only
    // camera pin wiring determines whether the sensor answers, and
    // config.json cannot be read yet anyway with the card unreachable.
    String camera_probe_diagnostic;
    const bool camera_reachable = camera.begin(AppConfig{}, camera_probe_diagnostic);
    fatal_error = camera_reachable
        ? "SD card not found. The camera itself is working, so check that a FAT32 SD card (32GB or smaller) is properly inserted. (" + diagnostic + ")"
        : "Camera and SD card are both unreachable. Check that the camera/SD board is firmly connected to the main board. (" + diagnostic + ")";
    // The phone app's own TRANSLATIONS table has an entry for each of these
    // two codes (see src/control_server.cpp) and renders that instead of
    // this raw string when present - fatal_error above still carries the
    // technical diagnostic for the serial log and for any other fatal_error
    // case, which has no code and falls back to showing it as-is.
    fatal_error_code = camera_reachable ? "sd_card_not_found" : "expansion_board_disconnected";
    return;
  }
  // storage.begin()'s own diagnostic (mount clock) was previously silently
  // discarded here - the next report() below overwrote it before it was
  // ever printed. Surfacing it now while investigating a totalBytes()
  // discrepancy between this boot-time mount and a later dev-bridge MOUNT
  // (29 August 2026, see docs/hardware-validation.md).
  report(diagnostic + " total=" + String(static_cast<unsigned long long>(storage.totalBytes())) +
         " used=" + String(static_cast<unsigned long long>(storage.usedBytes())));
  config = ConfigLoader::defaults();
  if (!ConfigLoader::load(storage.fs(), config, diagnostic)) { report("fatal configuration failure: " + diagnostic); fatal_error = "Bad configuration: " + diagnostic; return; }
  control_server.setEffectiveConfig(
      "{\"schema_version\":1,\"capture_fps\":" + String(config.capture_fps) +
      ",\"capture_interval_ms\":" + String(config.capture_interval_ms) +
      ",\"max_session_seconds\":" + String(config.max_session_seconds) +
      ",\"capture_mode\":\"" + config.capture_mode + "\",\"camera_preset\":\"" + config.camera_preset +
      "\",\"motion_trigger_enabled\":" + String(config.motion_trigger_enabled ? "true" : "false") +
      ",\"motion_threshold\":" + String(config.motion_threshold) +
      ",\"frame_size\":\"" + config.frame_size + "\",\"jpeg_quality\":" + String(config.jpeg_quality) +
      ",\"model_id\":\"" + config.model_id + "\",\"log_level\":\"" + config.log_level + "\"}");
  report(diagnostic);
  if (!camera.begin(config, diagnostic)) { report("fatal camera failure: " + diagnostic); fatal_error = "Camera failure: " + diagnostic; return; }
  report(diagnostic);
  if (!inference.begin(diagnostic)) { report("fatal inference failure: " + diagnostic); fatal_error = "Inference setup failure: " + diagnostic; return; }
  report(diagnostic);
  if (!logger.begin(storage, config, camera.sensorId(), diagnostic)) { report("fatal session setup failure: " + diagnostic); fatal_error = "Session setup failure: " + diagnostic; return; }
  report(diagnostic);
  performance_path = "/system/performance_" + logger.runId() + ".csv";
  ensurePerformanceLog();
  {
    const uint32_t warmup_wall_start_ms = millis();
    String seed_diagnostic;
    if (!camera.seedWhiteBalance(kWhiteBalanceSeedRedGain, kWhiteBalanceSeedGreenGain, kWhiteBalanceSeedBlueGain,
                                  seed_diagnostic)) {
      report("white-balance seed failed (" + seed_diagnostic + "), starting from AWB default instead");
    } else {
      report("camera warm-up: " + seed_diagnostic);
    }
    report("camera warm-up: pumping frames for " + String(kCameraWarmupMs / 1000) +
           "s so AWB walks from the seed to the actual current light");
    const uint32_t warmup_deadline = millis() + kCameraWarmupMs;
    uint32_t warmup_frames = 0;
    while (static_cast<int32_t>(millis() - warmup_deadline) < 0) {
      String warmup_diagnostic;
      camera_fb_t* warmup_frame = camera.capture(warmup_diagnostic);
      if (warmup_frame != nullptr) {
        camera.release(warmup_frame);
        ++warmup_frames;
      } else {
        delay(50);  // avoid a tight spin if a frame is briefly unavailable
      }
    }
    report("camera warm-up complete: " + String(warmup_frames) + " frames in " + String(kCameraWarmupMs / 1000) +
           "s (" + String(warmup_frames * 1000.0f / kCameraWarmupMs, 1) + " fps), " + camera.manualGainStatus());
    report("camera warm-up total wall time: " + String(millis() - warmup_wall_start_ms) + " ms");
  }
  session_started_ms = millis();
  next_capture_due_ms = session_started_ms;
  ready = true;
}

void loop() {
  control_server.handleClient();
  // Only acted on here, between captures, so a stop can never land mid-write.
  if (ready && !finished && control_server.consumeStopRequest()) finishSession();
  // config.json is only ever read once at boot, so writing it mid-session
  // has no effect on the current run - safe any time the card is mounted.
  String pending_config_json;
  if (!finished && fatal_error.isEmpty() && control_server.consumePendingConfigWrite(pending_config_json)) {
    String diagnostic;
    if (!storage.writeTextAtomic("/config.json", pending_config_json, diagnostic)) report("config write failed: " + diagnostic);
    else report("camera settings updated; takes effect after the board is restarted");
  }

  // Serial development bridge: only touches the card when capture is not
  // about to run this cycle (ready && !finished mirrors exactly the
  // condition that gates captureOnce() below), so it can never race a write.
  DevBridgeContext dev_context;
  dev_context.storage = &storage;
  dev_context.camera = &camera;
  dev_context.capturing = ready && !finished;
  dev_context.stop_session = []() { finishSession(); };
  dev_bridge.poll(dev_context);

  ControlStatus status;
  status.run_id = logger.runId();
  status.capture_count = logger.captureCount();
  status.saved_count = saved_image_count;
  status.sd_mounted = fatal_error.isEmpty() && !finished;
  status.error = fatal_error;
  status.error_code = fatal_error_code;
  status.elapsed_ms = ready ? (millis() - session_started_ms) : 0;
  status.state = !fatal_error.isEmpty() ? "error" : (!ready ? "warming_up" : (finished ? "safe_to_remove" : "capturing"));
  status.motion_recent_count = motion_history_count;
  const uint8_t oldest_offset = (motion_history_next + ControlStatus::kMotionHistoryCapacity - motion_history_count) %
                                 ControlStatus::kMotionHistoryCapacity;
  for (uint8_t index = 0; index < motion_history_count; ++index) {
    status.motion_recent[index] = motion_history[(oldest_offset + index) % ControlStatus::kMotionHistoryCapacity];
  }
  control_server.update(status);

  if (!ready || finished) { delay(100); return; }
  const uint32_t now = millis();
  if (config.max_session_seconds > 0 && now - session_started_ms >= config.max_session_seconds * 1000UL) { finishSession(); return; }
  if (static_cast<int32_t>(now - next_capture_due_ms) < 0) { delay(5); return; }
  const uint32_t scheduled_ms = next_capture_due_ms;
  next_capture_due_ms += config.capture_interval_ms;
  if (static_cast<int32_t>(now - next_capture_due_ms) >= 0) {
    report("capture cadence overrun; schedule rebased without backlog");
    next_capture_due_ms = now + config.capture_interval_ms;
  }
  captureOnce(scheduled_ms);
}

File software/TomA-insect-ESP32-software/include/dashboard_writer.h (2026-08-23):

#pragma once

#include <Arduino.h>

#include "inference.h"
#include "sd_storage.h"

struct DashboardCapture {
  String run_id;
  String capture_id;
  uint32_t uptime_ms = 0;
  String outcome;
  String image_path;
  uint16_t width = 0;
  uint16_t height = 0;
  size_t jpeg_bytes = 0;
  uint32_t capture_ms = 0;
  uint32_t inference_ms = 0;
  InferenceOutcome inference_outcome = InferenceOutcome::ModelUnavailable;
  float motion_score = -1.0F;
  float motion_threshold = 0.0F;
};

class DashboardWriter {
 public:
  bool begin(SdStorage& storage, String& diagnostic);
  bool appendCapture(const DashboardCapture& capture, String& diagnostic);
  bool finish(String& diagnostic);

 private:
  static constexpr uint16_t kChunkSize = 100;
  bool promoteCurrentChunk(String& diagnostic);
  bool recoverCurrentChunk(String& diagnostic);
  uint32_t countCurrentRecords(String& diagnostic) const;
  bool writeManifest(String& diagnostic);
  bool writeSummary(String& diagnostic);
  bool loadState(String& diagnostic);
  bool saveState(String& diagnostic);
  String currentChunkPath() const;
  String escapeJavaScript(const String& value) const;

  SdStorage* storage_ = nullptr;
  uint32_t closed_chunk_count_ = 0;
  uint32_t closed_capture_count_ = 0;
  uint32_t current_chunk_count_ = 0;
  uint32_t current_chunk_id_ = 1;
  String current_part_path_;
};

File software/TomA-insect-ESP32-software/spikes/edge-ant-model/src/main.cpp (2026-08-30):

// Step 1 of the spike: does the mixed `arduino, espidf` framework even
// compile and boot for this exact board? No ESP-DL yet - that's step 2,
// added only once this is proven. See docs/adr/0002-on-device-ant-edge-model.md.
#include <Arduino.h>

void setup() {
  Serial.begin(115200);
  delay(250);
  Serial.println("spike: arduino+espidf mixed framework boots");
}

void loop() {
  delay(1000);
}

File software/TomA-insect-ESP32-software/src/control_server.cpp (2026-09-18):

#include "control_server.h"

#include <WiFi.h>
#include <esp_heap_caps.h>
#include <esp_mac.h>

namespace {
constexpr uint8_t kDnsPort = 53;

// The last 4 hex digits (last two bytes) of the chip's factory-programmed,
// permanently unique MAC-derived ID - stable across reflashes, needs no
// per-unit setup step or bookkeeping, and the same firmware image produces a
// different, correct suffix on every board automatically.
//
// 18 September 2026: this used to read ESP.getEfuseMac() & 0xFFF, which
// looked right but wasn't - confirmed from cores/esp32/Esp.cpp,
// getEfuseMac() fills the uint64_t via esp_efuse_mac_get_default(uint8_t*),
// writing the MAC's bytes (first byte first) starting at the integer's
// lowest address. On this little-endian chip that puts the MAC's FIRST byte
// - the shared vendor/batch OUI, identical across most boards bought
// together for one kit - in the LOW bits that "& 0xFFF" reads, not the
// chip-unique LAST byte the comment always intended. Confirmed live: two
// boards from the same reel (E8:F6:0A:8B:A7:C4 and E8:F6:0A:8B:B4:20, same
// first two bytes) both produced InsectCam-6E8. Fixed by reading the MAC
// bytes directly instead of a bitmask of the packed integer whose byte order
// isn't what it looks like.
//
// Widened from 3 to 4 hex digits the same day: 4096 slots (3 digits) gives a
// ~30% chance of at least one collision in a 50-board kit (birthday-paradox
// math, n(n-1)/2m), even with the byte-order bug fixed - not safe enough for
// events at that scale. 65536 slots (4 digits, the full last two MAC bytes)
// brings that under 2% for the same 50 boards.
String wifiSuffix() {
  uint8_t mac[6] = {0};
  esp_efuse_mac_get_default(mac);
  const unsigned suffix_value = (static_cast<unsigned>(mac[4]) << 8) | mac[5];
  char suffix[5];
  snprintf(suffix, sizeof(suffix), "%04X", suffix_value);
  return String(suffix);
}

const char kControlAppHtml[] PROGMEM = R"HTML(<!doctype html>
<html lang="en">
<head>
<meta charset="utf-8">
<meta name="viewport" content="width=device-width, initial-scale=1">
<title>Your insect camera</title>
<style>
  :root { color-scheme: light; font-family: "Trebuchet MS", "Segoe UI", system-ui, sans-serif;
    --ink:#17324d; --muted:#557084; --cream:#fff8ed; --paper:#fff;
    --purple:#7356c7; --purple-dark:#4b318f; --teal:#087f82; --coral:#ef6f61; --coral-dark:#b34642;
    --green:#0f9d58; --green-dark:#0b7742; --shadow:0 10px 26px rgb(33 58 83/.12); }
  * { box-sizing:border-box; }
  body { margin:0; background:#e8eef0; color:var(--ink); display:flex; justify-content:center; padding:20px 12px 40px; }
  .phone { background:var(--cream); border-radius:26px; box-shadow:var(--shadow); overflow:hidden; width:100%; max-width:420px; }
  .bar { background:var(--purple); color:#fff; padding:16px 18px 14px; display:flex; align-items:center; gap:10px; }
  .bar-dot { width:.6rem; height:.6rem; border-radius:50%; background:#8ef0a8; flex:none; }
  .bar-title { font-weight:900; font-size:.98rem; }
  .bar-sub { font-size:.74rem; opacity:.85; margin-left:auto; font-weight:700; }
  .screen { padding:16px; display:grid; gap:12px; }
  .hero-card { background:linear-gradient(150deg,#7356c7,#5a3fae); color:#fff; border-radius:1.3rem; padding:18px; }
  .hero-eyebrow { font-size:.68rem; font-weight:900; letter-spacing:.14em; text-transform:uppercase; color:#f0e2ff; margin:0 0 6px; }
  .hero-count { font-size:2.9rem; font-weight:900; line-height:1; margin:0; }
  .hero-count small { font-size:.95rem; font-weight:800; opacity:.9; }
  .hero-time { margin:8px 0 0; font-size:.84rem; opacity:.92; }
  .note-card { background:var(--paper); border-radius:1.3rem; padding:15px 16px; box-shadow:var(--shadow); }
  .note-card h3 { margin:0 0 5px; font-size:.92rem; }
  .note-card p { margin:0; font-size:.8rem; color:var(--muted); line-height:1.55; }
  .offline-note { text-align:center; font-size:.72rem; color:#7a8b96; margin:4px 0 0; }
  button { font:inherit; cursor:pointer; border-radius:999px; font-weight:900; border:2px solid transparent;
    width:100%; padding:15px 18px; font-size:1rem; transition:transform .16s ease; }
  button:active { transform:translateY(2px); }
  button:disabled { opacity:.55; cursor:default; box-shadow:none; }
  .btn-finish { background:var(--coral); color:#fff; box-shadow:0 5px 0 var(--coral-dark); }
  .btn-again { background:var(--green); color:#fff; box-shadow:0 5px 0 var(--green-dark); max-width:19rem; margin:16px auto 0; }
  .finish-note { font-size:.74rem; color:var(--muted); text-align:center; margin:-4px 0 0; line-height:1.5; }
  .center-screen { flex:1; display:flex; flex-direction:column; align-items:center; justify-content:center;
    text-align:center; padding:34px 22px; gap:6px; }
  .big-emoji { font-size:3.4rem; line-height:1; margin-bottom:4px; }
  .center-screen h2 { margin:0; font-size:1.5rem; letter-spacing:-.02em; }
  .center-screen p { margin:0; color:var(--muted); font-size:.88rem; line-height:1.6; max-width:28ch; }
  .safe-banner { background:var(--green); color:#fff; border-radius:1.2rem; padding:16px 18px; width:100%; max-width:19rem; margin-top:10px; }
  .safe-banner strong { display:block; font-size:1rem; margin-bottom:3px; }
  .safe-banner span { font-size:.8rem; opacity:.95; line-height:1.5; display:block; }
  .peek-card { background:var(--paper); border-radius:1.3rem; padding:14px; box-shadow:var(--shadow); }
  .peek-stage { border-radius:.9rem; overflow:hidden; background:#15324d; aspect-ratio:4/3; display:flex; align-items:center; justify-content:center; margin-bottom:10px; }
  .peek-stage img { width:100%; height:100%; object-fit:cover; display:block; }
  .peek-empty { color:#b9cdd6; font-size:.8rem; font-weight:700; text-align:center; padding:18px; line-height:1.6; margin:0; }
  .btn-peek { background:#fff; border:2px solid var(--teal); color:#075c63; width:100%; padding:12px 14px; font-size:.92rem; }
  .meter-card { background:var(--paper); border-radius:1.3rem; padding:14px 16px 16px; box-shadow:var(--shadow); }
  .meter-head { display:flex; align-items:baseline; justify-content:space-between; margin-bottom:8px; }
  .meter-title { font-weight:900; font-size:.9rem; }
  .meter-verdict { font-size:.74rem; font-weight:900; color:#075c63; }
  .bars { display:flex; gap:3px; align-items:flex-end; height:38px; }
  .bars i { flex:1; background:#dfe9ec; border-radius:2px 2px 1px 1px; display:block; height:12%; font-style:normal;
    transition:height .45s ease, background .45s ease; }
  @media (prefers-reduced-motion: reduce) { .bars i { transition:none; } }
  .bars i.hot { background:var(--coral); }
  .bars i.warm { background:#f4bf38; }
  .settings-details { background:var(--paper); border-radius:1.3rem; box-shadow:var(--shadow); overflow:hidden; }
  .settings-details summary { padding:14px 16px; font-weight:900; font-size:.88rem; cursor:pointer; color:var(--purple-dark); }
  .settings-body { padding:0 16px 16px; display:grid; gap:10px; }
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

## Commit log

2026-07-31 Add camera logger platform scaffold
    [partitions.csv]
2026-08-12 Fix ESP32-S3 build configuration
    [partitions.csv]
2026-08-12 Avoid noisy missing-file SD errors
    [sd_storage.cpp]
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2026-08-12 Fix dashboard expand controls and close button
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2026-08-18 Add offline AntAI beta dashboard workflow
    [excluded_boundary_frames.csv, roboflow_import_vui-2026-08-18.csv, split_manifest.csv]
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2026-08-21 Fix motion-mode shard bug, add dashboard motion chart, prototype Wi-Fi control app
    Motion-triggered capture:
    - Fix shard directory only being created when the shard boundary happened
    to coincide with a retained capture; under motion mode most captures are
    skipped, so later shards were often silently never created and every
    save into them failed with image_write_failed. Now ensured per save.
    - Add motionScore/motionThreshold to the dashboard JS chunk format so the
    browser dashboard can show what the device measured (previously only in
    the raw CSV).
    - New "Motion watch" panel in dashboard.html: a log-scaled scatter of
    motion score vs time for the most recent session, auto-hidden wh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
    [control_server.cpp, dashboard_writer.h, install_dashboard_demo.py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]
2026-08-22 Add peek, live motion meter, camera settings and QR access to control app
    Completes phases 3-4 of docs/device-control-app-plan.md and the firmware
    half of phase 5. All confirmed working live on hardware except where noted.
    Phase 3 - peek and live motion:
    - GET /api/peek serves the most recent captured frame from a double-buffered
    PSRAM copy, with an atomic index swap so a reader never sees a half-written
    buffer. No SD read and no camera reconfiguration, so a peek cannot disturb
    capture or the motion baseline.
    - motionRecent[] added to /api/status: a ring buffer of recent motion scores,
    free to collect since the values are already computed per check. Drives an
    "is anything moving?"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
    [control_server.cpp, main.cpp]
2026-08-22 Add step-by-step setup guide for non-specialist users
    A complete walkthrough from bare board to viewing pictures, written for a
    teacher-level audience: comfortable with a computer, new to microcontrollers.
    Every command is given in full, and the reasoning behind the fiddly bits is
    explained rather than asserted.
    Covers installing Python and PlatformIO, getting the code, flashing the
    firmware, preparing the card, running a session, the Android control app,
    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
2026-08-23 Point setup guide at the kit-for-kids repository and record licensing
    The camera software is published inside the wider InsectAI COST Action
    Kit-for-Kids repository at software/TomA-insect-ESP32-software, so the
    setup guide's "get the code" step now reflects that: clone the whole
    project, then work inside that one folder, with a check that the reader
    is in the right directory before continuing.
    Also records licensing in the README (MIT via the host repository, with
    Mediabunny MPL-2.0 and FlatBug MIT noted separately), and corrects a
    stale comment in control_server.h that still described the AP password
    as MAC-derived after it became a fixed shared value.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
2026-08-23 Remove manually-copied camera software ahead of subtree import
    The camera software was previously copied into this repository by hand,
    losing its development history. Removing it here so the next commit can
    import it as a git subtree with its full history intact. No content is
    lost: the existing files are a strict subset of the version being
    imported.
    [partitions.csv]
2026-08-23 Add GitHub Pages site configuration
    Publishes the repository's documentation as a browsable site with the root
    README as the index, a navigation sidebar, and full-text search, using the
    Just the Docs theme via remote_theme.
    All navigation lives in _config.yml rather than YAML front matter inside the
    Markdown files. GitHub renders front matter as a table when browsing a .md
    file on github.com, so embedding it would clutter every document for anyone
    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
2026-08-23 Trim site navigation to externally useful documents and pin page URLs
    Two fixes.
    Navigation: the sidebar listed all sixteen camera-software documents,
    including development records such as the next-session checklist, hardware
    validation, and experiment write-ups. These are working notes rather than
    material for someone building or using a camera, so the navigation now shows
    six documents: setup guide, operations guide, camera specification,
    architecture, data schema, and model card.
    The remaining documents stay published rather than being dropped, because
    the kept pages link to them (the camera README points at the project brief
    and next-session checklist; the operations guide points at th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
2026-08-23 Pin README page URLs by disabling jekyll-readme-index
    Explicit permalinks worked for ordinary documents but were ignored on README
    pages: jekyll-readme-index claims those files before permalinks are applied,
    which is what pushed nested READMEs a directory level too high and left
    /camera-software/ returning 404 while /software/ served the camera README.
    Disabling the plugin and giving every README its own permalink, including
    the root one that serves as the site index, makes all page locations
    explicit and predictable.
2026-08-23 Restore jekyll-readme-index so README pages render again
    Disabling the plugin in the previous commit removed the site index and the
    section landing pages entirely: it is what converts each README.md into a
    page, so /, /camera-software/ and /models/ all became 404.
    Re-enabled, and the permalinks removed from the four README-backed entries
    since the plugin claims those pages before permalinks apply and they cannot
    be pinned. Ordinary documents keep their explicit permalinks, which do work.
    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
2026-08-27 Squashed 'software/TomA-insect-ESP32-software/' changes from a89097d..4aa2f58
    4aa2f58 Raise SD SPI clock from 4 MHz to 25 MHz, halving image write time
    git-subtree-dir: software/TomA-insect-ESP32-software
    git-subtree-split: 4aa2f588524ead927bd561101582dd3ac68e9287
2026-08-27 Squashed 'software/TomA-insect-ESP32-software/' changes from 4aa2f58..d09f98f
    d09f98f Add serial development bridge for unattended remote work
    git-subtree-split: d09f98f7b000ac437bb9cdeebd8eed119c85ad3d
    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
2026-08-27 Squashed 'software/TomA-insect-ESP32-software/' changes from d09f98f..5d3cb8d
    5d3cb8d Correct dev-bridge scope after verifying single-image retrieval
    git-subtree-split: 5d3cb8db9475698c0e201ca176c743277b140dea
    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
2026-08-27 Squashed 'software/TomA-insect-ESP32-software/' changes from 5d3cb8d..a0d18b2
    a0d18b2 Note stale ref *.lock files as part of the same sync gotcha
    db1145e Document the git-subtree publishing model in CLAUDE.md
    02d1381 Ignore local example-image and chat-archive folders
    git-subtree-split: a0d18b20b04f864efe9dda9751dafd3013ee8591
    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
2026-08-28 Squashed 'software/TomA-insect-ESP32-software/' changes from a0d18b2..1e9719a
    1e9719a Add <DEV PROGRESS> heartbeats so slow != stalled is no longer a guess
    46dd300 Add on-device AUDIT/RUNS commands; investigate large-CAT stall
    7c06e80 Record one-hour pilot run: 3589/3600 images, dark-room caveat
    git-subtree-split: 1e9719ab58cc1d11dd261f356120c49113304192
    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
    [dev_bridge.cpp, dev_bridge_client.py]
2026-08-30 Squashed 'software/TomA-insect-ESP32-software/' changes from 1e9719a..630cbfa
    630cbfa Add a priority-ordered hand-off summary to next-session.md
    3700c80 Add ADR 0002 and feasibility spike for on-device ant edge model
    c07c631 Rework dashboard front-page metrics; fix AI note; find SD totalBytes bug
    c56464d Record white-balance fix trial result: mechanism works, problem persists
    3c7cf01 Record the dashboard front-page metrics task for 29 August 10:00
    92e2f80 Attempt a fix for the repeated session-start white-balance cast
    bdf4277 Complete one-hour pilot acceptance with a daylight repeat
    872525a Decorrelate performance sampling from dashboard chunk promotion
    git-subtree-dir: software/TomA-insect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
    [camera_service.cpp, main.cpp, sd_storage.cpp]
2026-09-10 Update camera software: one-command new-device setup script
    Add tools/setup_device.py: auto-detects the board's serial port, wraps
    the PlatformIO upload, then prepares the SD card (dashboard, vendor
    files, folders, pilot config.json). Factor prepare_card() out of
    prepare_sd.py so the script and the standalone tool share one code path.
    Verified end to end on a fresh board + blank card: flash -> card prep ->
    boot -> config load -> QXGA capture -> safe stop -> consistent data
    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
2026-09-13 Squashed 'software/TomA-insect-ESP32-software/' changes from 630cbfa..9bdc42c
    9bdc42c Fix dashboard card-loading UX and performance; ship AI models by default
    222cdcc Record the daylight white-balance recheck: better, not fully solved
    b10fd8d Seed white balance from a measured value, then walk to actual light
    c934127 Add AWB gain read/write API; find why fast-mode warm-up didn't stick
    ef4d708 Warm up white balance in a fast low-res mode, not full capture resolution
    git-subtree-split: 9bdc42c55aebadd9e53a0221ce4fb85e05295475
    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
    [camera_service.cpp, install_ai_pack.py, main.cpp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]
2026-09-13 Squashed 'software/TomA-insect-ESP32-software/' changes from 9bdc42c..81d9288
    81d9288 Fix a second stale "Load images and AI" reference in operations.md
    git-subtree-split: 81d9288bc655310b378f302c5366c9a101247061
    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
2026-09-14 Squashed 'software/TomA-insect-ESP32-software/' changes from 81d9288..7d6eb37
    7d6eb37 Add Spanish language support across guide, dashboard, and phone app
    4fb84f3 Pull down setup_device.py and its dependents from the published repo
    git-subtree-split: 7d6eb37e037d3c69be0190e85b0a7c6017f2f5df
    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
2026-09-18 Squashed 'software/TomA-insect-ESP32-software/' changes from 7d6eb37..a5d8fb0
    a5d8fb0 Replace AntAI - Beta with AntAI - Test; make the rehearsal demo self-loading
    c9a2813 Fix per-board Wi-Fi name collisions caused by wrong MAC byte order
    d4d8c06 Add USB-C cable, reorder sections, and clarify assembly/AI steps in Barcelona guide
    082b0a5 Make each board's Wi-Fi network name unique, drop QR-code joining
    git-subtree-split: a5d8fb0c3561031960d9e2284882f3cff8beb6b0
    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
    [control_server.cpp, install_ai_pack.py, install_dashboard_demo.py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]
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2026-09-22 3D Printed Files
    [Base.stl, Bottom Column.stl, Cam Enclosure fix.stl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]
2026-09-22 Add files via upload
    First commit of structured Excel workbook used to track contributions to the InsectAI COST Action using the CRediT typology (https://credit.niso.org) with Victoria Burton as example.
    [InsectAI CRediT register.xlsx]
2026-09-23 Add files via upload
    Added README sheet with instructions how to use the spreadsheet
    [InsectAI CRediT register.xlsx]
2026-10-01 Squashed 'software/TomA-insect-ESP32-software/' changes from a5d8fb0..c392e11
    c392e11 Migrate from OV3660 to OV5640 camera sensor
    git-subtree-split: c392e117c143df0ab3fb34556d96b01d054bbaef
    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
2026-10-01 WIP: support both OV3660 and OV5640 cameras, add OV5640 continuous autofocus
    Dual-sensor support: a SensorProfile per supported camera (PID, name,
    white-balance seed, whether that seed was measured on it, autofocus).
    The detected sensor is named in the boot report and run manifest; an
    unrecognised PID still captures but skips the white-balance register
    writes. The OV5640 seed is borrowed from OV3660 and flagged provisional.
    camera_trial_report.py now shows each run's sensor.
    OV5640 continuous autofocus: firmware vendored unchanged from Espressif's
    esp32-camera (commit 1d73d881b, Apache-2.0, include/vendor/), control
    sequence ported because the pinned framework predates it. Uses the full
    ACK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
    [camera_service.cpp, camera_trial_report.py, configure_camera_trial.py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]
2026-10-02 WIP: OV5640 autofocus confirmed, background phone peek, 10 MHz XCLK and lower Wi-Fi power for heat
    Daylight session, 2 October 2026, OV5640 board on COM4:
    - Continuous autofocus confirmed working (owner watched it refocus; status
    0x20 behaves as "settled"). The continuous command needs the full ACK
    handshake for release and is accepted on a focusing status.
    - Phone peek reworked: buffer raised to 512 KB (OV5640 daylight frames
    reach ~445 KB and were silently skipped), and a 512x384 re-encode is
    built by a core-0 worker instead of sending the full frame from the
    capture loop. The decode pauses every ~50 ms so the task watchdog stays
    fed. Tested: 38 peeks, 707/707 frames, interval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
    [camera_service.cpp, control_server.cpp, main.cpp]
2026-10-14 Pi Zero 2 W camera: scripted card flashing, first boot and camera confirmed
    New exploratory software/pi-zero-cam/ on branch Pi-zero-cam3, as an
    alternative to the XIAO ESP32S3 Sense, whose OV5640 overheats (the Sense
    board feeds its core from a 1.3 V regulator, below the sensor's spec, so it
    runs its internal regulator).
    tools/flash_card.py prepares cards without the Imager GUI: downloads the
    pinned Raspberry Pi OS Lite 64-bit (Trixie, 2026-10-06), checks
    Raspberry Pi's published SHA-256, writes it with rpi-imager --cli, then
    writes cloud-init user-data (hostname, user pi with SSH key only, SSH on,
    rpi-usb-gadget USB networking) and an empty network-config (no Wi-Fi
    credentials on the card)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
2026-10-14 Pi camera: phone app, hotspot, automatic drive/capture mode
    insectcam/service.py: camera (main stream for photos, lores stream for a
    ~20 KB peek in ~7 ms) and a session service the phone drives (warming_up ->
    capturing -> safe_to_remove; start again without rebooting; elapsed time
    frozen after finish).
    insectcam/control.py: the shared phone page (extracted from the ESP32
    firmware by tools/extract_control_app.py) with the same /api endpoints,
    states and error codes; settings validated, motion refused with a clear
    message (not built on the Pi yet).
    pi/install.sh: idempotent install (packages, services, photo drive, hotspot
    InsectCam-<last 4 of serial> / antcamera with captive-portal DNS).
    pi/i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
2026-10-15 Pi camera: motion mode
    insectcam/motion.py reproduces the XIAO firmware's motion score (8x6 tiles,
    brightness-compensated grayscale difference, strongest tile, threshold 5) on
    the camera's own 640x360 luma stream block-averaged to 160x90, with no sensor
    re-initialisation, so autofocus/exposure/white balance keep running. Checks
    that see no change are recorded as motion_not_detected rows with no photo and
    skip the JPEG encode; the phone app's motion switch and motion meter now work.
    Records, manifest and dashboard fields match the XIAO's.
    Verified: 11 unit tests (tests/test_motion.py); on the Pi, 68 checks gave 18
    photos (baseline plus 17 while waving a hand) and 50 motion_not_detected; quie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
2026-10-15 Pi camera: detector module (ONNX ant detector, worker, drawing)
    insectcam/detector.py: onnxruntime detector that reads input size and class
    names from the model (so a retrained model drops in) and understands both the
    provided [1,4+nc,N] layout (with NMS) and YOLO26's end-to-end [1,300,6];
    letterbox/decode/NMS written here (no Ultralytics code on the camera); PIL
    YUV420->RGB (numpy version cost 90-150 ms on the Pi); DetectorWorker with a
    one-slot mailbox where capture jobs beat best-effort live-view jobs, so
    recording and live view cannot oversubscribe the cores; drawing helper that
    burns boxes and a PLACEHOLDER MODEL banner into a frame. tools/edge_bench.py
    now imports the shared functions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
2026-10-15 Pi camera: live view backend (detector-annotated MJPEG stream)
    insectcam/live.py: a producer thread, running only while a phone watches, takes
    the newest 640x360 frame, gives it to the DetectorWorker as a best-effort job
    (capture-frame jobs always win, and the producer does not even grab frames while
    the detector is busy), burns boxes and the PLACEHOLDER banner into it and
    publishes the JPEG. The detector is shared with recording when that is on,
    otherwise the live view loads its own and frees it when the last viewer leaves.
    GET /api/live is a multipart/x-mixed-replace stream: max 2 viewers (503
    live_busy), 409 live_not_available / no_model_installed, ends at 10 minutes or
    when the session e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
2026-10-15 Pi camera: live view in the phone app, and the detection switch
    The frame delivery is now one annotated JPEG per request (GET
    /api/live/frame, a long-poll with X-Seq, plus POST /api/live/stop), not a
    multipart MJPEG stream: tested 15 October 2026, current Chromium/Edge (155)
    do not show multipart/x-mixed-replace in an <img> in any of four format
    variants. A viewer is a random id sent with each request and counts as
    watching while requests keep arriving, so a phone that vanishes frees its slot
    after 6 s and no connection has to be tracked; max 2 viewers (503
    live_busy), 10 minutes per viewing session (409 live_time_up), 409
    live_not_available / no_model_installed.
    insectcam/pi_extras.html is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
2026-10-16 Audit: flag zero-byte images as errors
    A power cut after a photo was renamed but before its size reached the card left
    named, empty files that the audit counted as present (Pi camera, 16 October 2026).
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2026-10-16 Dashboard: show on-camera detector results (boxes overlay, per-photo counts, per-adventure summary)
    New edge-results.js, hidden unless a card's records carry a model: frame-viewer
    overlay with a score slider and a TEST MODEL banner burned in, gallery badge, table
    columns and filters, an adventure summary with charts, and a corrected card note
    (the old one said the camera never runs AI whenever any row was model_unavailable).
    Boxes load lazily from data/detections_NNNNNN.js. XIAO cards are unchanged.
    Tested end to end in Edge against cards written by the real Pi writer.
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2026-10-16 Revert "Dashboard: compare the camera's boxes with a browser model on one picture"
    This reverts commit 43fbd6ecd0df55396ff54eb0de486d151378d321.
2026-10-16 Stop tracking Python bytecode (committed by mistake with the Pi camera code)

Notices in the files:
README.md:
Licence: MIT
